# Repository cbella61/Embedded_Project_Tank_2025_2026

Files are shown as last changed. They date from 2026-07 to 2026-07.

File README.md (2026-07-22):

# Wi-Fi Remote-Controlled Tank

Embedded project for a Wi-Fi remote-controlled tank. An ESP32 controller reads two joysticks and two buttons, then sends UDP commands to an Arduino Uno R4 WiFi mounted on the tank. The Arduino controls the tracks, turret rotation and elevation, and the cannon relay.

> YouTube video: [Project demonstration](https://youtu.be/Sw5uwZuhA9w)

> Project presentation: [Group presentation](docs/tank_wifi_embedded_project.pdf)

## Features

- differential drive for the two tracks.
- horizontal turret rotation using a stepper motor.
- turret elevation using two mirrored servo motors.
- logical zeroing of turret and elevation.
- relay control with a limited pulse and cooldown interval.
- Wi-Fi/UDP communication between the controller and the tank.
- safe stop and rearming after a communication loss.
- editable CAD model and exports for manufacturing/3D printing.

## Requirements

### Hardware

The project uses the following hardware components:

| Quantity | Component | Purpose |
| ---: | --- | --- |
| 1 | Arduino Uno R4 WiFi | Tank controller and Wi-Fi access point |
| 1 | ESP32 Dev Module | Handheld controller |
| 1 | Emakefun PS2X & Motor Drive Board | Drives the DC motors and servos; includes a PCA9685 PWM chip |
| 2 | DC motors with tracks | Tank movement |
| 1 | 28BYJ-48 stepper motor with driver | Horizontal turret rotation |
| 2 | TowerPro SG90 servos, or equivalent | Turret elevation |
| 2 | Analog joystick modules | Driving, turret rotation, and elevation |
| 2 | Momentary push buttons | Zeroing and relay control |
| 1 | 5 V relay module | Controls the cannon load |
| 1 | 7.4 V battery | Tank and servo power supply |
| - | Wires, connectors, screws, and printed parts | Wiring and mechanical assembly |

For pin assignments, power supply, jumpers, and safety precautions, see the [wiring guide](docs/tank_shield_wiring_guide.md) and its [PDF version](docs/tank_shield_wiring_guide.pdf).

### Software

- [Visual Studio Code](https://code.visualstudio.com/) with the PlatformIO extension, or PlatformIO Core.
- Arduino framework, installed automatically by PlatformIO.
- appropriate USB drivers for the serial ports of both boards.
- [Autodesk Fusion 360](https://www.autodesk.com/products/fusion-360/overview) on Windows or alternative softwares (like [FreeCAD](https://www.freecad.org/)) on Linux, to design and edit the CAD model.
- [OrcaSlicer](https://github.com/SoftFever/OrcaSlicer) to prepare the parts for 3D printing.

The repository includes the project's application code, including the local `PWMController` and `motorController` drivers. Platform dependencies (Arduino core, WiFiS3, and WiFi/ESP32) are provided by the PlatformIO-selected frameworks and are not duplicated in this repository.

### Tools used by the team

- Visual Studio Code and PlatformIO for firmware development and upload.
- Autodesk Fusion 360 for the mechanical CAD design and editable assemblies.
- OrcaSlicer for slicing and preparing the components for 3D printing.

## Project Layout

```text
.
├── tank/                       # Arduino Uno R4 WiFi firmware on the tank
│   ├── src/                    # UDP receiver, tracks, turret, and relay
│   └── lib/                    # Local PCA9685 and motor-shield drivers
├── controller-esp32/           # ESP32 handheld-controller firmware
│   └── src/                    # Joystick reading and UDP transmission
├── cad/                        # Source files, editable assemblies, and 3D exports
│   ├── source/                 # Parametric Fusion 360/OpenSCAD sources
│   ├── stl/                    # 3D-printable parts
│   └── reference/              # Technical notes and component references
├── docs/                       # Project presentation, wiring guide and motor-shield manual
└── README.md                   # This guide
```

## Essential Wiring

| Function | Connection |
| --- | --- |
| Left track | Shield port `M3` |
| Right track | Shield port `M1` |
| Turret stepper driver | Arduino `D2`–`D5` to `IN1`–`IN4`, with a common GND |
| Elevation servo A | Shield port `S5` |
| Elevation servo B | Shield port `S6` |
| Relay | `D7` signal, 5 V, and GND |
| Controller joystick 1 | ESP32 GPIO `34` and `32` |
| Controller joystick 2 | ESP32 GPIO `35` and `33` |
| Zero button | ESP32 GPIO `25` to GND |
| Fire button | ESP32 GPIO `26` to GND |

Do not power motors and servos from USB alone. Before the first test, lift the tracks off the ground and follow the verification section of the [wiring guide](docs/tank_shield_wiring_guide.md).

## Build, Flash, and Run

### 1. Setup

1. Clone the repository and open its root folder in VS Code/PlatformIO.
2. Connect the Arduino Uno R4 WiFi to the PC using USB.
3. Connect the ESP32 to the PC using USB.
4. Verify that the hardware connections match the wiring guide.

### 2. Build

From PowerShell in the repository root:

```powershell
pio run -d tank
pio run -d controller-esp32
```

Alternatively, use the **Build** command in PlatformIO after opening `tank` and `controller-esp32`, respectively.

### 3. Flash

Upload each firmware to its corresponding board:

```powershell
pio run -d tank --target upload
pio run -d controller-esp32 --target upload
```

If both boards are connected, select the correct serial port in PlatformIO or temporarily add `upload_port` to the relevant `platformio.ini` file.

### 4. Run

1. Power the tank on: the Arduino and shield initialize the motors and create the `Tank_AP` access point on UDP port `4210`.
2. Power the ESP32 controller on while keeping both joysticks centered.
3. The controller calibrates the joysticks and connects to `Tank_AP` automatically.
4. Once the system receives consecutive neutral commands, the actuators are armed.

## User Guide

| Control | Action |
| --- | --- |
| Joy1 Y | Forward/reverse driving |
| Joy1 X | Differential steering or turn-in-place |
| Joy2 X | Horizontal turret rotation |
| Joy2 Y | Raise/lower the turret |
| Zero button (GPIO25) | Sets the logical zero position of turret and elevation |
| Fire button (GPIO26) | Activates a 200 ms relay pulse |

The relay only accepts a new command after a 12-second cooldown. If the tank does not receive valid UDP packets within the configured timeout, it stops motion and disables the relay. After a timeout or reconnection, release the buttons and center the joysticks to allow rearming.

## Documentation and Materials

- [Editable wiring guide](docs/tank_shield_wiring_guide.md)
- [Wiring guide PDF](docs/tank_shield_wiring_guide.pdf)
- [Emakefun PS2X & Motor Drive Board manual](docs/PS2X_MotorDriveBoard_InstructionManual_V1.4.pdf)
- [YouTube project demonstration](https://youtu.be/Sw5uwZuhA9w)

## Team Members and Contributions

Most of the project work was carried out collaboratively by the whole team. The file and subsystem division below identifies the main responsibility or the most significant contribution of each member; it is not intended to imply that the other members did not participate in, review, test, or support those activities.

| Team member | Contribution |
| --- | --- |
| Francesco Martellla | `controller-esp32/src/main.cpp` and `tank/src/main.cpp`, technical drawing, CAD work with Alice and Selmir, 3D-printing work with Alice |
| Alice Sedioli | `controller-esp32/src/joystickReader.*`, `controller-esp32/src/udpSender.*`, and `tank/src/udpReceiver.*`, UDP communication with Selmir and Christian, CAD work with Francesco and Selmir, 3D-printing work with Francesco |
| Christian Bella | `tank/lib/PWMController/*` and `tank/lib/motorController/*`; UDP communication with Alice and Selmir, component selection, local hardware-library implementation |
| Selmir Kusi | `tank/src/servoTorretta.*` and `tank/src/trackController.*`, UDP communication with Alice and Christian, turret and track control, CAD work with Alice and Francesco |

### Shared contributions

- **Technical drawing:** Francesco prepared the technical drawings.
- **Component selection:** Christian contributed to selecting the electronic and electromechanical components.
- **CAD design:** Alice, Selmir, and Francesco collaborated on the Fusion 360 model design.
- **3D printing:** Alice and Francesco prepared the parts' models using OrcaSlicer and printed them at FabLab UniTrento.
- **UDP communication:** Alice, Selmir, and Christian collaborated on the communication path between the ESP32 controller and the Arduino tank, including packet transmission, reception, and safe timeout behavior.
- **Turret and tracks:** Selmir implemented the turret and track-control logic.
- **Libraries:** Christian implemented the local PWM and motor-control libraries used by the tank firmware.

## License

See [LICENSE](docs/license).

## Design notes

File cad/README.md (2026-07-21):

# Tank 3D model
This folder contains the editable mechanical model of the tank.

## Folder structure

- `source/`: parametric sources and the native Autodesk Fusion file.
- `stl/`: parts ready for 3D printing, generated only after dimension confirmation.
- `reference/`: table of confirmed dimensions and assembly notes.

The model is divided into components:

1. lower deck with battery, Arduino, and DC motor cable routing;
2. upper deck with driver, turret PCB, and vertical cable passage;
3. rotating turret base driven by the stepper motor;
4. upper tilting support actuated by two servos;
5. straight cannon fixed to the tilting section, excluding the lateral straps/bars
   shown in the reference.

## Official mechanical references

The official Arduino UNO R4 WiFi STEP model is kept in
`reference/vendor/arduino_uno_r4_wifi/`. It is used only as a dimensional reference.

The TowerPro SG90 dimensions and the manufacturer link are in
`reference/vendor/towerpro_sg90/README.md`.

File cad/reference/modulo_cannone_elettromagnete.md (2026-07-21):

# Cannon module with electromagnet

## Confirmed functional requirements

- The PCB with the electromagnet, its mechanism and the barrel must be
  embedded in the moving part of the turret.
- This entire assembly must rotate together with the cradle driven by the two
  servos.
- Existing holes on the PCB must be used for attachment; do not invent a
  different drilling pattern.
- The stepper still rotates the entire turret in the XY plane.
- The 50 x 50 x 2 mm PCB of the firing module is part of the moving group.

## Confirmed dimensions

- base material/type: PCB, not a metal plate;
- PCB: 50 x 50 x 2 mm;
- diameter of the four holes: 3.5 mm;
- center of each hole 5 mm from the two adjacent PCB edges; coordinates from
  the PCB center are therefore X = ±20 mm and Y = ±20 mm;
- complete cannon in the solenoid area: maximum external diameter 20 mm;
- cylindrical/tubular barrel: external diameter 10 mm and wall thickness 1 mm,
  therefore internal diameter 8 mm;
- barrel protrusion from the cannon exit: 46 mm;
- total height from the PCB bottom face to the top of the assembly: 23 mm.

- lateral envelope of the electromagnet body: about 25 mm;
- width shown in the top view: about 30 mm;

These last values must not be used yet to generate geometry.

## Assembly choice to verify on prototype

The PCB will be centered on the moving cradle and fastened using the four
confirmed holes. The final position of the elevation axis relative to the
module can be adjusted in the parameters after verifying the real balance.

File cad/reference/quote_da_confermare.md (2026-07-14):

# Quote da confermare

Unità di progetto: millimetri.

| Gruppo | Quota | Valore confermato |
| --- | --- | --- |
| Telaio | Lunghezza totale del piano inferiore | 170 mm (comunicata come "height") |
| Telaio | Larghezza totale del piano inferiore | 160 mm |
| Telaio | Spessore del piano inferiore | 3 mm |
| Telaio | Luce verticale tra superficie superiore del piano inferiore e fondo del piano superiore | 40 mm |
| Fissaggio | Numero colonnine | 4 |
| Fissaggio | Diametro esterno colonnine | 10 mm (scelta autorizzata) |
| Fissaggio | Distanza centro colonnine dai bordi | 12 mm (scelta autorizzata) |
| Fissaggio | Viteria | M3 |
| Viteria disponibile | Misure utilizzabili | M2, M2.5, M3, M4 e M5; scegliere in base al componente |
| Fissaggio | Diametro fori passanti | 3,2 mm |
| Fissaggio | Sede dado M3 | 5,8 mm tra facce, profondità 2,6 mm |
| Fissaggio | Posizione sede dado M3 | In cima a ogni colonnina |
| Fissaggio al telaio | Metodo | Fascette attorno a due aste trasversali |
| Fissaggio al telaio | Dimensioni asole | 10 x 5 mm, asse lungo Est-Ovest |
| Fissaggio al telaio | Posizioni asole dal bordo Sud | 10, 25, 75 e 90 mm, allineamento laterale centrale |
| Piano superiore | Lunghezza | 170 mm |
| Piano superiore | Larghezza | 160 mm |
| Piano superiore | Spessore | 3 mm |
| Passacavi | Diametro e posizione del foro inferiore | da confermare |
| Passacavi | Diametro e posizione del foro superiore | da confermare |
| Elettronica | Modello e ingombro della batteria | da confermare |
| Elettronica | Arduino | UNO R4 WiFi ABX00087 con shield Emakefun sovrapposta; profilo ufficiale 68,58 x 53,34 mm, quattro fori Ø3,2 mm; STEP ufficiale disponibile |
| Elettronica | Apertura Arduino | una apertura quadrata 25 x 25 mm nel piano superiore, sopra S1-S8 e D2-D7; centro X=33,33 mm, Y=45,71 mm |
| Elettronica | Passaggio pacco batteria PCB cannone | 60 x 33 mm nel piano superiore, centro X=-52,5 mm, Y=-15 mm; case fotografato 59 x 32 mm, gioco 0,5 mm per lato, lato lungo verso Nord |
| Elettronica | Posizione supporto batteria | angolo Sud-Ovest; lato da 100 mm verso Nord, 5 mm da Ovest e 20 mm da Sud; centro X=-52,5 mm, Y=-15 mm |
| Elettronica | Supporto batteria nello stage completo | pareti 2,5 mm alte 17 mm unite al piano inferiore; il piano da 3 mm è il fondo; nessuna vite o colla dedicata |
| Elettronica | Supporto batteria autonomo | stage alternativo con fondo proprio da 2 mm; ingombro 100 x 45 x 19 mm |
| Elettronica | Apertura cavi supporto batteria | tratto utile di 10 mm sulla parete lunga Est, subito dopo la parete corta Sud |
| Elettronica | Posizione Arduino + shield | angolo Nord-Est, rotazione 90 gradi antioraria, jack DC verso Sud; 20 mm da Est e 5 mm da Nord; centro X=33,33 mm, Y=45,71 mm |
| Elettronica | Modello e ingombro del driver motori | da confermare |
| Elettronica | Dimensioni e schema dei fori della PCB torretta | da confermare |
| Torretta | Riferimento stepper | 28BYJ-48, quote CAD provvisorie e modificabili |
| Torretta | Base rotante | diametro 70 mm, spessore 6 mm, provvisoria |
| Elevazione | Servomotori | 2 TowerPro SG90 coricati, corpo 22,7 x 12,2 x 27 mm; inserimento laterale removibile |
| Elevazione | Fissaggio SG90 | due slitte esterne e due barrette M2.5 per lato; zona centrale libera per il cavo |
| Elevazione | Cinematica | due perni orizzontali coassiali, diametro 6 mm; movimento del cannone lungo Z |
| Elevazione | Corsa proposta | -10° / +35°, da verificare sul prototipo |
| Azimut | Corsa torretta | da -180° a +180° rispetto allo zero; 360° complessivi ma non continui |
| Azimut | Arresto | gestito dal software contando i passi dello stepper; nessuna battuta meccanica nel CAD |
| Cablaggio SG90 | Cavo, connettore e passaggi | 2 cavi, ciascuno a 3 fili, profilo circa 4 x 1 mm; uscita slitta 5 x 2 mm; connettore 7 x 3 mm; passaggio comune 8 x 6 mm, connettori infilati uno alla volta |
| Cablaggio cannone | Fili, connettore e passaggio mobile | 2 fili allungabili; connettore 5 x 3 mm; passaggio sotto culla 6 x 4 mm |
| Cablaggio torretta | Guida azimut | canale anulare completo tipo clock-spring, raggio medio 28 mm, larghezza libera 8 mm, fondo continuo Z locale 20-23 mm, altezza libera 7 mm e uscita fissa 8 x 6 mm a 45°; nessuna razza nella pista |
| Cannone | Forma | unico corpo rettilineo solidale alla culla mobile |
| Cannone | Lunghezza e sezione esterna | 175 x 40 x 14 mm, asse a 70 mm dal retro; provvisorio |
| Modulo di sparo | Parti mobili | piastra con elettromagnete, meccanismo e canna ruotano tutti con la culla |
| Modulo di sparo | Metodo di fissaggio | usare i quattro fori esistenti della PCB mobile |
| Modulo di sparo | PCB | 50 x 50 x 2 mm, non metallica |
| Modulo di sparo | Zona con solenoide | cannone completo Ø20 mm in questa zona |
| Modulo di sparo | Canna | tubolare, Ø10 mm esterno, parete 1 mm, Ø8 mm interno, sporgenza 46 mm dall'uscita |
| Modulo di sparo | Altezza complessiva | 23 mm dalla faccia inferiore della PCB alla sommità |
| Modulo di sparo | Fori PCB | Ø3,5 mm; centri a 5 mm dai due bordi adiacenti; interassi 40 x 40 mm |

## Regola di modellazione

Ogni valore inserito nel CAD deve essere riconducibile a una misura comunicata
e confermata oppure a una prima proposta espressamente autorizzata e marcata
come provvisoria. Eventuali giochi di stampa sono parametri separati e dichiarati.

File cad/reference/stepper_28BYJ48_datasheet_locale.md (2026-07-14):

# Riferimento locale stepper 28BYJ-48

Fonte analizzata il 13 luglio 2026:
`C:\Users\selmi\Downloads\stepper.pdf`.

Il PDF è un datasheet generico del **28BYJ-48 5 V**. È utile come riferimento,
ma non sostituisce la misura del motore fisico perché esistono varianti tra
produttori.

## Quote leggibili nel disegno

- corpo cilindrico: Ø28 mm;
- profondità nominale del corpo: 19 mm;
- interasse dei due fori: 35 ± 0,2 mm;
- due fori nominali: Ø4,2 mm;
- raggio esterno delle alette attorno ai fori: R3,5 mm;
- albero nominale: Ø5 mm con una faccia piana;
- quota trasversale della parte piatta: 3 mm nel disegno;
- sporgenza complessiva albero: 10 ± 0,5 mm;
- tratto utile indicato: 6 ± 0,2 mm;
- collare frontale indicato: 1,5 mm.

Il disegno conferma quindi i valori provvisori già usati per interasse 35 mm e
fori Ø4,2 mm. Non conferma invece che l'esemplare reale dell'utente abbia
esattamente la stessa faccia piana e la stessa sporgenza.

## Conseguenza per l'adattatore

Un foro tondo Ø5,3 mm non può trasmettere la coppia dello stepper. Per il
prototipo serve una delle seguenti soluzioni, da scegliere dopo la misura
dell'albero reale:

1. sede a D aderente all'albero;
2. mozzo con grano laterale;
3. mozzo a morsetto diviso.

Prima di modificare il CAD vanno misurati sul motore fisico:

- diametro massimo dell'albero;
- distanza tra faccia piana e lato opposto;
- lunghezza utile realmente inseribile nel mozzo.

## Vecchio riferimento disponibile

È presente anche
`C:\Users\selmi\Downloads\Carroarmato\STL\adattatore_stepper_torretta_v2_3_RC2.stl`.
La mesh ha ingombro circa 73 x 63,22 x 22 mm ed è utile come riferimento
geometrico, ma non è parametrica e le sue quote interne non vanno considerate
confermate senza confronto con il motore reale.

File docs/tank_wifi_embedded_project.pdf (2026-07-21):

EMBEDDED SYSTEMS PROJECT A.A. 2025-26

# Remotely controlled tank

Wireless manual control with explicit software safety states.
Fully functional, network-controlled robotic vehicle with articulated movement and precise aiming capabilities.

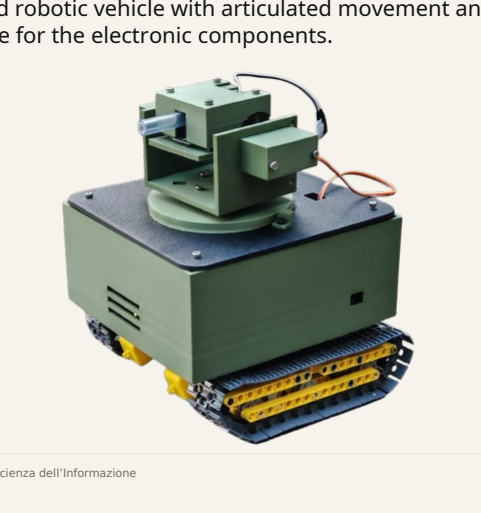
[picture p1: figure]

Featuring a custom 3D printed case for the electronic components.

Università degli Studi di Trento · Dipartimento di Ingegneria e Scienza dell’Informazione | 01

EMBEDDED SYSTEMS PROJECT A.A. 2025-26

# Hardware components overview

- Arduino Uno R4 WiFi: Main microcontroller and web server host.
- ESP32-DevKitC-32UE: Microcontroller used for the remote control.

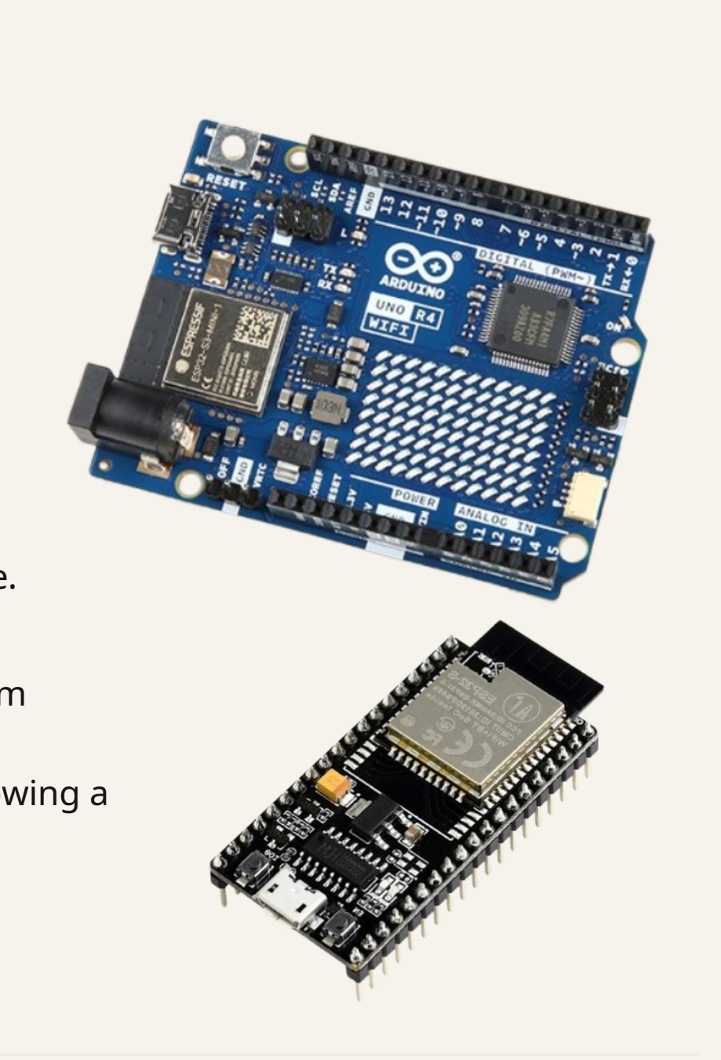
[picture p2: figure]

- EmakeFun PS2X & Motor Drive Board: Primary motor driver interface.
- DC Motors (2x): Independent track movement.
- Servomotors (2x): Vertical inclination of the cannon muzzle (maximum vertical rotation: 45 ). °
- Stepper Motor & Driver: Lateral/horizontal rotation of the turret, allowing a rotation of 45 on both sides. °
- HV Electromagnetic Cannon DIY Kit: Main firing mechanism (DC3V).
- Battery: 3300mAh capacity, 7.4V.
Hardware overview | 01

# Architecture overview

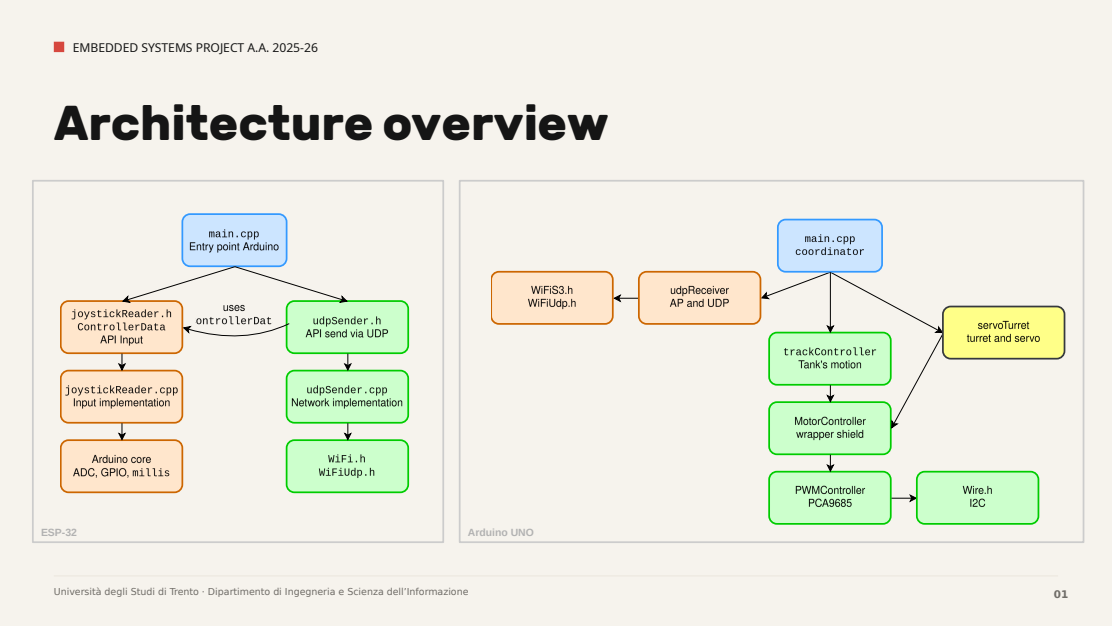
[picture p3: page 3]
ESP-32; Arduino UNO

EMBEDDED SYSTEMS PROJECT A.A. 2025-26

# Code showcase

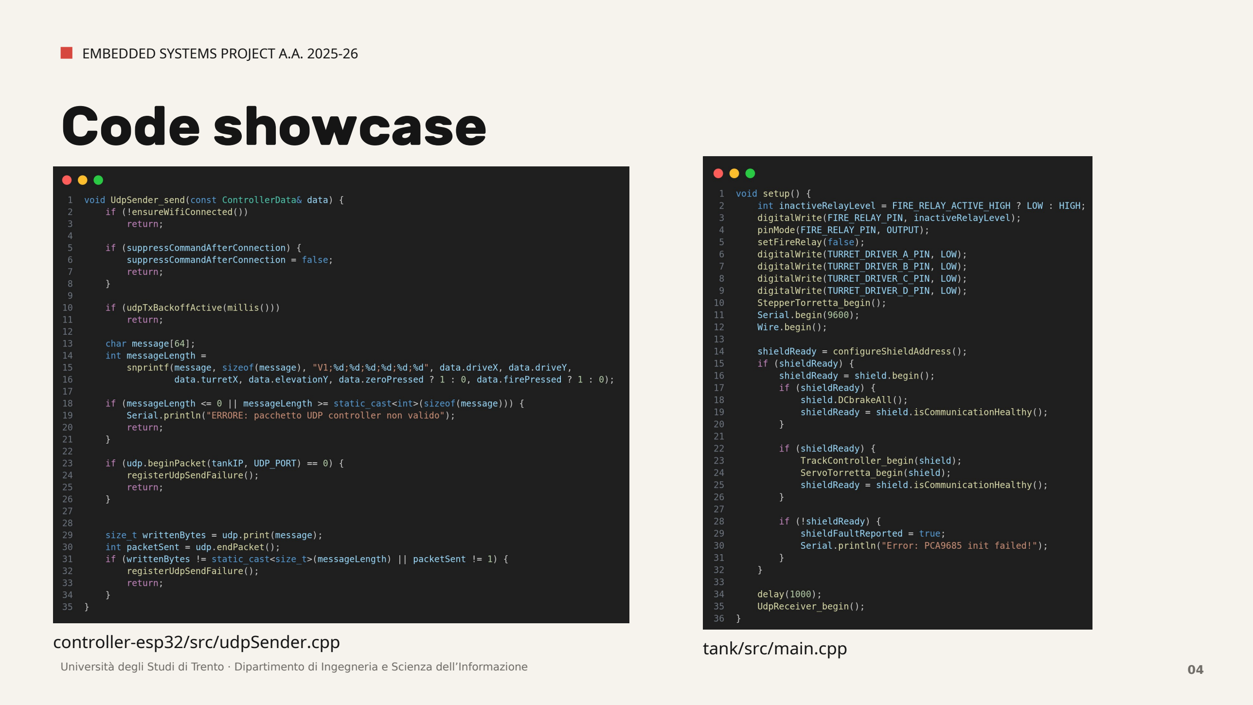
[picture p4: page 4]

EMBEDDED SYSTEMS PROJECT A.A. 2025-26

Università degli Studi di Trento · Dipartimento di Ingegneria e Scienza dell’Informazione | 04
controller-esp32/src/udpSender.cpp | tank/src/main.cpp

EMBEDDED SYSTEMS PROJECT A.A. 2025-26

# Testing

Università degli Studi di Trento · Dipartimento di Ingegneria e Scienza dell’Informazione | 05
- Physical device: checking if actual result = desired result;
- | Serial monitor: checking log messages using pio device monitor command; “ | ”
- Wireshark: UDP packet sniffing to check protocol integrity.

# Results

- Physical device: tank works as intended;
- UDP protocol: works fine in low-traffic networks; delays happen only if the device is around networks with 20+
| devices.

EMBEDDED SYSTEMS PROJECT A.A. 2025-26

# Improvements and future work

01
WEB
INTERFACE

Basic HTML/CSS
dashboard using
Arduino Uno R4 WiFi's
web server capabilities.
Adds flexibility and is
easier to debug.

02
FPV CAMERA

Adding an ESP32-CAM
or a dedicated FPV
camera for better
aiming and driving.
The video feed would be
separate from the
control data (Wi-Fi for
control, analog/2.4GHz
for video).

03
TARGET
DISTANCE
MEASUREMENT
Using an ultrasound
sensor and an
accelerometer to
calculate the tank's
distance from the
target and turret
incline.

04
AUTOMATED
FIRING SYSTEM

Implementation of a
state machine for
automatic loading and
firing of the cannon.
Università degli Studi di Trento · Dipartimento di Ingegneria e Scienza dell’Informazione | 06

05
UDP V2

Congestion control,
Forward Error
Correction (FEC), and
multipath support.

EMBEDDED SYSTEMS PROJECT A.A. 2025-26

# Thanks for the attention

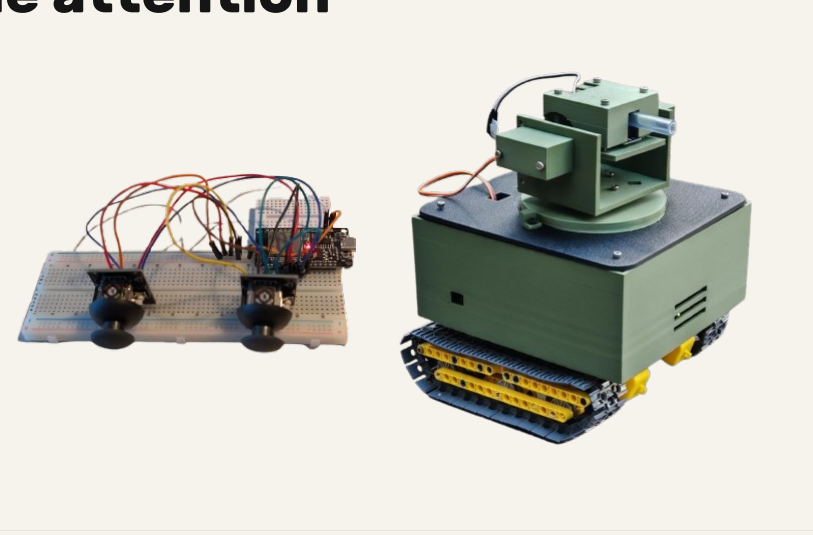
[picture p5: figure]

Team members:
- Christian BELLA
- Selmir KUSI
- Francesco MARTELLA
- Alice SEDIOLI

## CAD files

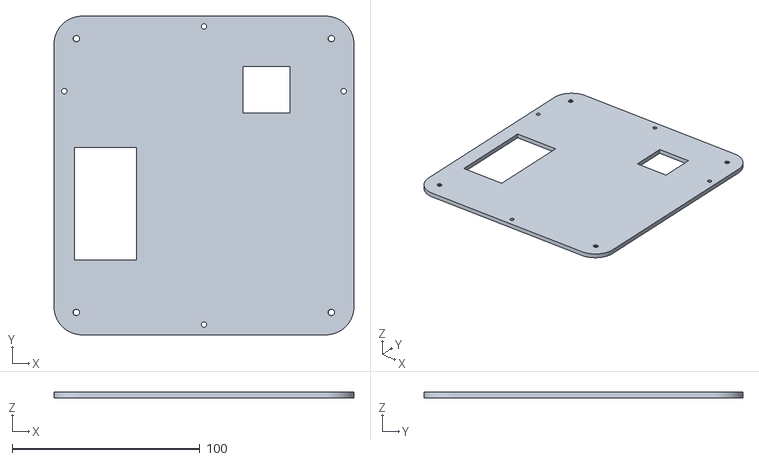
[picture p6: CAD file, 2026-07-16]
cad/stl/02_Piano_superiore.stl
160.0 x 170.0 x 3.00

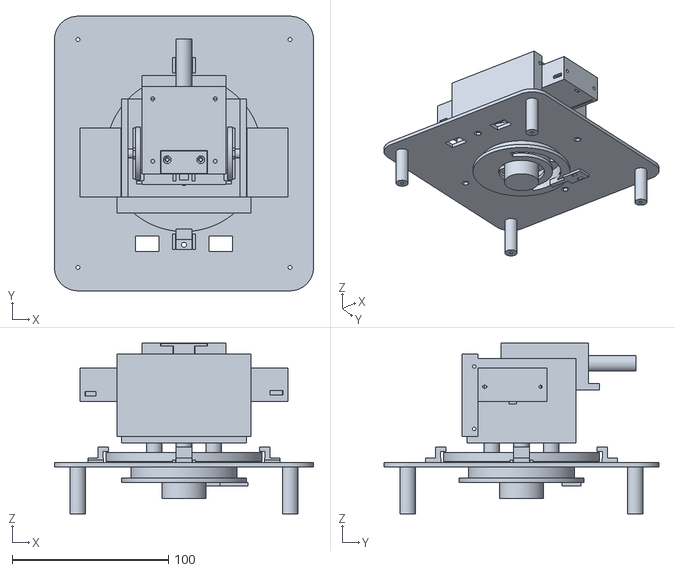
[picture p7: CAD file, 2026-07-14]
cad/stl/Torret_funzionale.stl
166.0 x 176.0 x 109.5

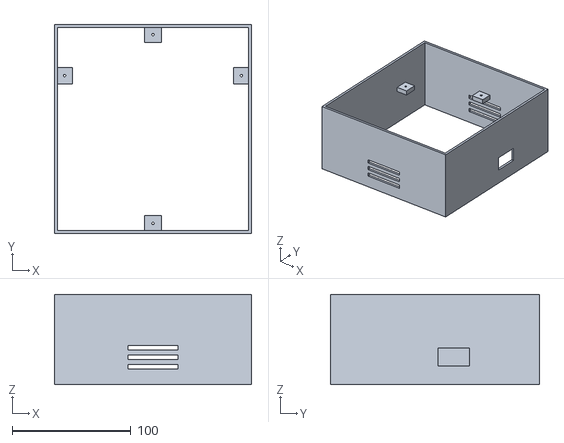
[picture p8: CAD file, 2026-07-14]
cad/stl/03_Guscio_laterale_continuo_carro.stl
166.0 x 176.0 x 76.0

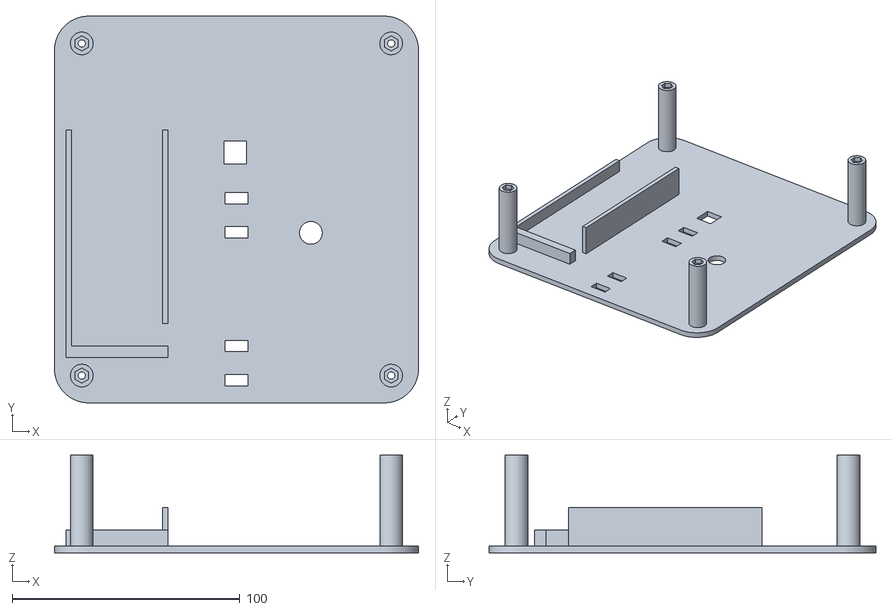
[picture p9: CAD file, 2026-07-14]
cad/stl/01_Piano_inferiore_colonnine_M3_supporto_batteria_integrato.stl
160.0 x 170.0 x 43.0

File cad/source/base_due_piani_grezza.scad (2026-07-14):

// Assieme grezzo dei due piani: solo quote confermate.
// Nessun foro e nessuna colonnina vengono aggiunti senza autorizzazione.
// Unita: millimetri.

piano_lunghezza = 170;
piano_larghezza = 160;
piano_spessore = 3;
luce_tra_piani = 40;

module piano() {
    translate([-piano_larghezza / 2, -piano_lunghezza / 2, 0])
        cube([piano_larghezza, piano_lunghezza, piano_spessore]);
}

color("LightSteelBlue")
    piano();

color("Gainsboro")
    translate([0, 0, piano_spessore + luce_tra_piani])
        piano();

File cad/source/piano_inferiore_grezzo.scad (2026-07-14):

// Piano inferiore grezzo: quote confermate, nessun foro ancora quotato.
// Unita: millimetri.

piano_lunghezza = 170;
piano_larghezza = 160;
piano_spessore = 3;

// Origine al centro della faccia inferiore.
translate([-piano_larghezza / 2, -piano_lunghezza / 2, 0])
    cube([piano_larghezza, piano_lunghezza, piano_spessore]);

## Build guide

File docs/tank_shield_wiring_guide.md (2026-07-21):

# Tank Shield - Wiring Guide and Configuration

Firmware: `Embedded_Project_Tank_2025_2026`  
Tank: Arduino Uno R4 WiFi + Emakefun PS2X & Motor Drive Board  
Controller: ESP32 Dev Module  
Updated: July 19, 2026

## 1. General map

| Function | Connection | Notes |
| --- | --- | --- |
| Left track | Shield `M3` | 2-wire DC motor |
| Right track | Shield `M1` | 2-wire DC motor |
| Unused port | Shield `M2` | Left unused because on tested hardware it rotated by itself |
| Horizontal turret | `D2-D5` to driver `IN1-IN4` | 5-wire stepper with external driver |
| Elevation servo A | Shield `S5` | Logical angle direct `0-47` degrees |
| Elevation servo B | Shield `S6` | Mirrored motion: `90 - angle` |
| Cannon relay | `D7` to relay `S` pin | Power terminals `COM` and `NO` |
| Communication | WiFi AP + UDP | `Tank_AP`, password `12345678`, port `4210` |

Motors and servos are driven by the shield. The horizontal turret and the
relay use Arduino digital pins routed via the shield connectors.

## 2. DC tracks

Each yellow motor has two wires and must use both terminals of the same motor
port. Do not connect one motor wire to GND.

| Track | Port | Connection |
| --- | --- | --- |
| Left | `M3` | Two motor wires into the two terminals of `M3` |
| Right | `M1` | Two motor wires into the two terminals of `M1` |

If a track spins in the wrong direction, swap its two wires or change in
`tank/src/trackController.h`:

```cpp
#define LEFT_TRACK_INVERTED false
#define RIGHT_TRACK_INVERTED false
```

Set `true` only for the side that needs to reverse direction.

## 3. Horizontal turret

The 5-wire stepper is not connected directly to the shield: its external driver
powers the coils. Arduino only sends the digital sequence on the four inputs.

| Arduino/shield | Turret driver |
| --- | --- |
| `D2` | `A` / `IN1` |
| `D3` | `B` / `IN2` |
| `D4` | `C` / `IN3` |
| `D5` | `D` / `IN4` |
| `GND` | `GND` driver |

Power the driver with the voltage required by its module. Its GND must be
connected to the common GND of Arduino, shield, ESP32 and any power supplies
connected via cable and the buck converter.

The firmware uses a single-phase full-step sequence:

```text
A -> B -> C -> D -> A       rotation one direction
D -> C -> B -> A -> D       rotation the other direction
```

Speed depends on `TURRET_STEP_INTERVAL_MS` in `tank/src/servoTorreta.h`:
higher values slow the turret. Current value is `2 ms`.

## 4. Elevation servos

The servo connector on the shield has three pins: `G` = ground, `V` = supply,
`S` = signal. Always check the letters printed on the board before inserting
the connector.

| Servo | Port | Current command |
| --- | --- | --- |
| Servo A | `S5` | from `0` to `47` degrees |
| Servo B | `S6` | from `90` to `43` degrees, i.e. `90 - angle A` |

The value shown on the tank serial is the logical angle of servo A. Servo B
automatically receives the mirrored command.

Configuration in `tank/src/servoTorreta.cpp`:

```cpp
#define ELEVATION_MIN_ANGLE 0
#define ELEVATION_MAX_ANGLE 47
#define ELEVATION_MIRROR_BASE 90
```

## 5. Relay and cannon

### Control side

| Relay | Arduino/shield |
| --- | --- |
| `+` | `5V` |
| `-` | `GND` |
| `S` | `D7` |

### Power side

Use `COM` and `NO`, not `NC`:

```text
cannon positive supply -> COM relay
NO relay                    -> cannon positive input
negative supply             -> cannon negative input
```

Looking at the module as in the project photo, the upper terminal toward the
cannon is `NO`. Always verify the `NO/COM/NC` labeling on the PCB before
powering.

The relay receives a `200 ms` pulse. At least `12 seconds` must elapse between
two firings, even if the button is pressed multiple times.

## 6. ESP32 controller

### Physical connections

| Component | Physical input | ESP32 pin |
| --- | --- | --- |
| Joy1 drive | X axis | GPIO `34` |
| Joy1 drive | Y axis | GPIO `32` |
| Joy2 turret | X axis | GPIO `35` |
| Joy2 turret | Y axis | GPIO `33` |
| Zero button | signal | GPIO `25`, button to GND |
| Fire button | signal | GPIO `26`, button to GND |

Buttons use `INPUT_PULLUP`: released = HIGH, pressed = LOW.

### Swap X/Y in software

Joysticks are mounted rotated. The firmware swaps X and Y on both:

```cpp
#define DRIVE_SWAP_X_Y true
#define TURRET_SWAP_X_Y true
```

After the swap, logical commands sent over UDP are:

| Logical command | Read physical pin | Function |
| --- | --- | --- |
| `driveX` | GPIO `32` | differential steering |
| `driveY` | GPIO `34` | forward/backward |
| `turretX` | GPIO `33` | horizontal turret |
| `elevationY` | GPIO `35` | elevation servo |

To invert only the direction of an axis use the four constants
`DRIVE_X_INVERTED`, `DRIVE_Y_INVERTED`, `TURRET_X_INVERTED` and
`ELEVATION_Y_INVERTED` in `controller-esp32/src/joystickReader.cpp`. Joy1 axis
orientation is corrected only here; on the tank only the two physical motor
inversions remain (`LEFT/RIGHT_TRACK_INVERTED`).

## 7. Joystick calibration

On ESP32 startup:

1. Leave both joysticks centered.
2. Firmware waits `600 ms`.
3. Reads each axis `80` times, 2 ms apart, and computes the real center. Full
   calibration therefore takes about `1.24 s` plus small processing overhead.
4. Calibration is accepted only if each axis is near `512` (maximum deviation
   `70`) and does not oscillate more than `40` points during sampling.
5. Remaps the measured center to `512`, keeping extremes `0-1023`. If
   calibration is invalid, only the safe command is sent and a restart with
   joysticks centered is required.
6. Even with valid calibration, before arming the controls it requires neutral
   joysticks and released buttons for `400 ms`.

Deadzones are not all equal: each filter serves a different purpose.

| Filter | Value and dead zone |
| --- | --- |
| Joy1 drive on controller | `DRIVE_INPUT_DEADZONE = 20`: less than `20` points from calibrated center |
| Joy2 turret/elevation on controller | `TURRET_INPUT_DEADZONE = 80`: less than `80` points from calibrated center |
| Tracks on the tank | `TRACK_COMMAND_DEADZONE = 100`: less than `100` points from UDP center, before and after mixing |
| Turret and servos on the tank | `TURRET_JOYSTICK_DEADZONE = 200`: less than `200` points from UDP center |

The small Joy1 deadzone avoids adding an excessive dead zone to the tank
protection. Do not touch joysticks during initial calibration and during the
arming wait.

## 8. Differential drive and speed

Joy1 Y controls forward/backward linearly and can reach maximum speed. Joy1 X
controls steering only. There are no additional curves, bands or intermediate
steering thresholds.

```text
forward  = decode(driveY)
turn     = decode(driveX)
left     = constrain(forward + turn, -512, +512)
right    = constrain(forward - turn, -512, +512)
```

`decode()` scales the input from `0-1023`, subtracts center `512` and applies
the tank deadzone. With joystick Y forward both tracks get the same command;
with Joy1 X one side speeds up and the other slows down. With only Joy1 X the
two tracks turn in opposite directions and the tank spins in place. `constrain()`
prevents the sum from exceeding the allowed command range.

Main configurations in `tank/src/trackController.h`:

```cpp
#define TRACK_COMMAND_DEADZONE 100
#define LEFT_TRACK_MIN_PWM 900
#define RIGHT_TRACK_MIN_PWM 900
```

When a reverse command is requested, each track is first braked to zero PWM and
re-enabled after `30 ms` (`TRACK_REVERSE_DEAD_TIME_MS` in
`tank/src/trackController.cpp`). The pause applies even if the joystick briefly
passes through center before the opposite direction.

## 9. UDP protocol and rate

The controller sends about `50 packets per second`, one every `20 ms`:

```text
V1;driveX;driveY;turretX;elevationY;zero;fire
```

Example:

```text
V1;512;900;512;512;0;0
```

The tank keeps the last valid command. If it does not receive valid packets for
`200 ms` it centers all axes, deactivates buttons and stops movements. On the
first timeout it returns the safe command before performing a new `WiFiS3`
polling, so it does not intentionally add a network wait to the normal stop.

On startup the tank remains disarmed. If `WiFi.beginAP()` or opening the UDP
socket fail, it does not enter `while(true)`: it remains in the safe state and
retries every `3 seconds`. When AP and UDP are ready, and after any boot,
timeout or network fault, the tank requests `3` consecutive packets with all
axes within `+/-20` of center and buttons released before rearming actuators.

If the ESP32 loses `Tank_AP`, it does not block the program: it stops sending,
tries to reconnect every `3 seconds` and allows the tank to enter the safety
timeout. When WiFi returns it updates the IP from the gateway, reopens UDP on
port `4210`, requests controller neutrality again and resumes sending only after
rearming.

The ESP32 error `endPacket(): could not send data: 12` is `ENOMEM`: a WiFi
stack buffer is temporarily exhausted, it is not a V1 string overflow. An
isolated error leaves the socket open; after `3` consecutive failures the
controller closes the socket and tries to reopen it after `200 ms` without
forcing an immediate WiFi reconnection. Radio sleep is disabled to reduce
latency. If it appears together with `WiFi lost`, check power and motor
electrical noise first: software cannot eliminate brown-out or EMI.

## 10. Power

According to the Emakefun V1.4 manual:

- the shield can be powered from the Arduino DC jack with `6-12 V`;
- a `7.4 V` battery on the Arduino jack is therefore within the expected range;
- with the servo jumper at `5V`, servos use the shield's 5 V regulator;
- with the jumper at `EX`, servos use the external power input;
- the manual specifies up to `3 A` for the shield's 5 V rail, but the actual
  consumption of the two servos depends on load and stall peaks.

Recommended configuration when servos jerk or reset Arduino:

```text
battery 7.4 V -> Arduino DC jack
battery 7.4 V -> buck converter input
buck regulated output -> shield external servo power
servo jumper -> EX
GND buck -> GND Arduino/shield
```

Adjust and measure the buck output before connecting servos. Use the voltage
allowed by the servos, typically 5-6 V. Do not connect two different supplies
to the same positive rail and do not power motors or servos from USB alone.

For WiFi problems during driving, keep logic/controller power separate from the
motor branch when possible, with a correct common ground. Add a suitable
electrolytic nearby the shield (approx. 470--1000 uF, correct voltage and
polarity), bypass ceramics and noise-suppression capacitors at motor terminals;
twist motor wires and keep them away from the ESP32 antenna. Before adding
components, verify current and voltage limits of battery, shield and motors.

> Important: a software timeout is not an electrical switch. To guarantee a
stop even if WiFiS3/I2C block or the Uno resets, provide a hardware enable/OE/
STBY default-off, or an E-stop that physically removes motor and relay enable.

## 11. Where to change behavior

| Change | File | Constant/function |
| --- | --- | --- |
| Swap X/Y Joy1 | `controller-esp32/src/joystickReader.cpp` | `DRIVE_SWAP_X_Y` |
| Swap X/Y Joy2 | `controller-esp32/src/joystickReader.cpp` | `TURRET_SWAP_X_Y` |
| Invert an axis | `controller-esp32/src/joystickReader.cpp` | constants `*_INVERTED` |
| Joy1 deadzone (drive) | `controller-esp32/src/joystickReader.cpp` | `DRIVE_INPUT_DEADZONE` |
| Joy2 deadzone | `controller-esp32/src/joystickReader.cpp` | `TURRET_INPUT_DEADZONE` |
| Track deadzone | `tank/src/trackController.h` | `TRACK_COMMAND_DEADZONE` |
| Single track speed | `tank/src/trackController.h` | `LEFT/RIGHT_TRACK_MIN/MAX_PWM`, `LEFT/RIGHT_TRACK_PWM_PERCENT` |
| Pause before reversing | `tank/src/trackController.cpp` | `TRACK_REVERSE_DEAD_TIME_MS` |
| Track direction | `tank/src/trackController.h` | `LEFT/RIGHT_TRACK_INVERTED` |
| Turret speed | `tank/src/servoTorreta.h` | `TURRET_STEP_INTERVAL_MS` |
| Elevation limits | `tank/src/servoTorreta.cpp` | `ELEVATION_MIN/MAX_ANGLE` |
| Mirror second servo | `tank/src/servoTorreta.cpp` | `ELEVATION_MIRROR_BASE` |
| Relay pulse duration | `tank/src/main.cpp` | `FIRE_RELAY_PULSE_MS` |
| Pause between shots | `tank/src/main.cpp` | `FIRE_RELAY_COOLDOWN_MS` |
| Tank AP/UDP retry | `tank/src/udpReceiver.cpp` | `NETWORK_RETRY_INTERVAL_MS` |
| Tank UDP rearm | `tank/src/udpReceiver.cpp` | `REARM_NEUTRAL_PACKET_COUNT`, `REARM_NEUTRAL_TOLERANCE` |
| UDP timeout | `tank/src/udpReceiver.cpp` | `CONNECTION_TIMEOUT_MS` |
| Controller send rate | `controller-esp32/src/main.cpp` | `UDP_SEND_INTERVAL_MS` |
| ESP32 `ENOMEM` recovery | `controller-esp32/src/udpSender.cpp` | `UDP_SEND_FAILURE_LIMIT`, `UDP_SOCKET_RECOVERY_INTERVAL_MS` |
| Track I2C refresh | `tank/src/trackController.h` | `TRACK_COMMAND_REFRESH_INTERVAL_MS` |

## 12. Quick diagram

```text
ESP32 controller
  GPIO34 <- Joy1 physical X -> driveY after swap
  GPIO32 <- Joy1 physical Y -> driveX after swap
  GPIO35 <- Joy2 physical X -> elevationY after swap
  GPIO33 <- Joy2 physical Y -> turretX after swap
  GPIO25 <- zero button to GND
  GPIO26 <- fire button to GND
                 |
                 | WiFi UDP, every 20 ms
                 v
Arduino Uno R4 WiFi + shield
  M3     -> left track DC motor, both wires
  M1     -> right track DC motor, both wires
  D2-D5  -> IN1-IN4 turret stepper driver
  S5     -> elevation servo A
  S6     -> elevation servo B
  D7     -> S relay cannon
  Relay  -> COM + NO, NO toward cannon
```

## 13. Pre-power checks

- No motor wire connected directly to GND.
- Turret driver and Arduino share common GND.
- Servo connectors oriented according to `G/V/S` printed on the shield.
- Measure the buck converter with a multimeter before connecting servos.
- Servo jumper set consistently: `5V` or `EX`.
- Relay connected to `COM` and `NO`, not to `NC`.
- Joysticks centered during ESP32 startup.
- Tracks lifted for the first test of timeout or `ENOMEM` recovery.
- Measure controller supply while tracks start/reverse; if `WiFi lost` appears,
  fix the power branch and wiring first.

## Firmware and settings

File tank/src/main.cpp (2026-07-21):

/*
 * TANK MAIN
 *
 * This file does not directly perform all movements: it coordinates modules.
 *
 * Operation method:
 * 1. In setup() initialize the relay, turret, PCA9685 shield and UDP receiver.
 * 2. In loop() read the last command received from the ESP32 controller.
 * 3. Dispatch each part of the command to the appropriate module:
 *    - driveX/driveY     -> differential tracks
 *    - turretX           -> horizontal turret D2-D5
 *    - elevationY        -> servos S5/S6
 *    - firePressed       -> relay D7
 *    - zeroPressed       -> logical zeroing
 * 4. If the controller stops sending packets for too long, stop the motors.
 */

#include <Arduino.h>
#include <Wire.h>

#include "motorController.h"
#include "servoTorreta.h"
#include "trackController.h"
#include "udpReceiver.h"

// Digital pin connected to the relay module.
#define FIRE_RELAY_PIN 7

#define FIRE_RELAY_PIN 7

// true: relay active with HIGH. false: relay active with LOW.
#define FIRE_RELAY_ACTIVE_HIGH true

// Duration of the fire pulse: the relay is not kept continuously on.
#define FIRE_RELAY_PULSE_MS 200

// Minimum time between one shot and the next.
#define FIRE_RELAY_COOLDOWN_MS 12000

// ===== SERIAL MONITOR =====

// Print coordinates once per second to avoid filling the console.
#define COORDINATE_PRINT_INTERVAL_MS 1000

// Shared PCA9685 shield between the tracks and elevation servo.
// Frequency is 50 Hz because it is compatible with servos.
static MotorController shield(50);

// Diventa true solo se la PCA9685 viene trovata su I2C.
static bool shieldReady = false;
static bool shieldFaultReported = false;

// Stato del relay sparo.
static bool fireRelayActive = false;
static unsigned long fireRelayStartTime = 0;
static unsigned long lastFireShotTime = 0;
static bool fireRelayHasShot = false;

// Check whether a device responds at an I2C address.
static bool i2cDevicePresent(uint8_t address) {
    Wire.beginTransmission(address);
    return Wire.endTransmission() == 0;
}

// Automatically select the PCA9685 address on the shield.
// Some shields use different addresses, so the code tries common ones.
static bool configureShieldAddress() {
    static const uint8_t candidateAddresses[] = {0x60, 0x40, 0x7F};

    for (uint8_t address : candidateAddresses) {
        if (i2cDevicePresent(address)) {
            shield.setAddress(address);
            Serial.print("Shield PCA9685: I2C 0x");
            Serial.println(address, HEX);
            return true;
        }
    }

    Serial.println("ERROR: PCA9685 shield not detected");
    return false;
}

// Set the correct electrical level for the fire relay.
static void setFireRelay(bool active) {
    int level =
        active ? (FIRE_RELAY_ACTIVE_HIGH ? HIGH : LOW) : (FIRE_RELAY_ACTIVE_HIGH ? LOW : HIGH);

    digitalWrite(FIRE_RELAY_PIN, level);
    fireRelayActive = active;
}

// Generate a single fire pulse for each button press.
// Uses the rising edge and then waits 12 seconds before accepting another shot.
static void updateFireRelay(bool firePressed, bool connected) {
    static bool lastFirePressed = false;
    static bool fireInputArmed = false;

    // After timeout or loss of connection the relay must turn off immediately.
    // A subsequent connection cannot reuse a button press that remained active:
    // first observe the release of the Fire button.
    if (!connected) {
        setFireRelay(false);
        fireInputArmed = false;
        lastFirePressed = false;
        return;
    }

    if (!fireInputArmed) {
        if (!firePressed) {
            fireInputArmed = true;
        }

        // Still record the received level: when Fire is held down
        // during reconnection it will not be interpreted as a rising edge.
        lastFirePressed = firePressed;
        return;
    }

    bool newFirePress = firePressed && !lastFirePressed;
    bool cooldownFinished =
        !fireRelayHasShot || millis() - lastFireShotTime >= FIRE_RELAY_COOLDOWN_MS;

    if (newFirePress && cooldownFinished) {
        setFireRelay(true);
        fireRelayStartTime = millis();
        lastFireShotTime = fireRelayStartTime;
        fireRelayHasShot = true;
    }

    if (fireRelayActive && millis() - fireRelayStartTime >= FIRE_RELAY_PULSE_MS) {
        setFireRelay(false);
    }

    lastFirePressed = firePressed;
}

// Stop all motion in case of UDP timeout.
// Tracks depend on the shield; the turret (D2-D5) can be stopped at any time.
static void stopAllMotion() {
    // TrackController_stop() e' innocua prima dell'inizializzazione e va tentata anche
    // dopo un fault I2C: una PCA9685 che ha conservato l'ultimo PWM puo' essere tornata
    // raggiungibile per un istante. Il controller limita internamente i retry di brake.
    TrackController_stop();
    StepperTorretta_stop();
}

// A NACK or a short I2C read makes the tank disarmed until reset.
// Do not attempt to automatically rearm a PCA9685 that has just reported an error.
static void enterShieldFault() {
    if (!shieldReady) {
        return;
    }

    // Spegni prima le uscite che non dipendono da I2C e tenta l'ultimo brake della
    // PCA9685 prima di segnare la shield come non utilizzabile.
    setFireRelay(false);
    StepperTorretta_stop();
    TrackController_stop();
    shieldReady = false;

    if (!shieldFaultReported) {
        shieldFaultReported = true;
        Serial.println("ERROR: PCA9685 communication; tank disarmed until reset");
    }
}

void setup() {
    // Preload the GPIO latches in a safe state before making them outputs.
    // This way D7 and D2-D5 do not wait for Serial or boot delay to receive the
    // first level defined by the firmware.
    int inactiveRelayLevel = FIRE_RELAY_ACTIVE_HIGH ? LOW : HIGH;
    digitalWrite(FIRE_RELAY_PIN, inactiveRelayLevel);
    pinMode(FIRE_RELAY_PIN, OUTPUT);
    setFireRelay(false);

    digitalWrite(TURRET_DRIVER_A_PIN, LOW);
    digitalWrite(TURRET_DRIVER_B_PIN, LOW);
    digitalWrite(TURRET_DRIVER_C_PIN, LOW);
    digitalWrite(TURRET_DRIVER_D_PIN, LOW);
    StepperTorretta_begin();

    Serial.begin(9600);

    // Initialize and brake the PCA9685 before the serial delay: after a reset
    // the PWM board can briefly retain the last command to the tracks.
    Wire.begin();
    shieldReady = configureShieldAddress();
    if (shieldReady) {
        // Avvia PWM, spegne le uscite motore e passa la shield ai moduli.
        shieldReady = shield.begin();
        if (shieldReady) {
            shield.DCbrakeAll();
            shieldReady = shield.isCommunicationHealthy();
        }

        if (shieldReady) {
            TrackController_begin(shield);
            ServoTorretta_begin(shield);
            shieldReady = shield.isCommunicationHealthy();
        }

        if (!shieldReady) {
            shieldFaultReported = true;
                    Serial.println("ERROR: PCA9685 initialization failed; tank disarmed");
        }
    }

    // The delay is only for the serial console; it should not delay motor braking.
    delay(1000);

    // Start WiFi access point and UDP reception.
    UdpReceiver_begin();
    Serial.println("Tank ready");
}

void loop() {
    // Riceve l'ultimo comando del controller ESP32.
    // Se non arrivano pacchetti, UdpReceiver_update() restituisce valori sicuri centrati.
    TankCommand command = UdpReceiver_update();

    // The release of Zero must be observed after boot or reconnection before
    // accepting a new press event.
    static bool lastZeroPressed = false;
    static bool zeroInputArmed = false;

    // Non inviare alcun nuovo comando agli attuatori se il link e' scaduto.
    // Spegnimento relay e arresto vengono eseguiti prima di ogni altro aggiornamento.
    if (!command.connected || !shieldReady) {
        setFireRelay(false);
        stopAllMotion();
        updateFireRelay(false, false);
        lastZeroPressed = false;
        zeroInputArmed = false;

        if (shieldReady && !shield.isCommunicationHealthy()) {
            enterShieldFault();
        }
    } else {
        // The horizontal turret is direct: uses D2-D5, so it does not depend on the PCA9685.
        StepperTorretta_updateJoystick(command.turretX);
        // Tracks and elevation depend on the PWM shield.
        if (!shieldReady) {
            shieldFaultReported = true;
            Serial.println("ERROR: PCA9685 communication; tank disarmed until reset");
        }
            } else {
                ServoTorretta_updateJoystick(command.elevationY);
                if (!shield.isCommunicationHealthy()) {
                    enterShieldFault();
                }
            }
        }

        // Fire e Zero restano inibiti se una scrittura PWM ha appena fallito.
        if (shieldReady) {
            updateFireRelay(command.firePressed, true);

            // Zero resets the turret logical position once per press.
            // After a reconnection, a press that is already held is ignored until release.
            if (!zeroInputArmed) {
                if (!command.zeroPressed) {
                    zeroInputArmed = true;
                }
                lastZeroPressed = command.zeroPressed;
            } else {
                if (command.zeroPressed && !lastZeroPressed) {
                    StepperTorretta_setZero();
                    ServoTorretta_setZero();
                }
                lastZeroPressed = command.zeroPressed;
            }
        } else {
            updateFireRelay(false, false);
            lastZeroPressed = false;
            zeroInputArmed = false;
        }
    }

    // Mostra coordinate e stato connessione una volta al secondo.
    static unsigned long lastPrintTime = 0;
    if (millis() - lastPrintTime > COORDINATE_PRINT_INTERVAL_MS) {
        lastPrintTime = millis();

        Serial.print("RX ");
        Serial.print(command.connected && shieldReady ? "OK" : "DISARMED");
        Serial.print(" | drive X=");
        Serial.print(command.driveX);
        Serial.print(" Y=");
        Serial.print(command.driveY);
        Serial.print(" | turret X=");
        Serial.print(command.turretX);
        Serial.print(" angolo=");
        Serial.print(StepperTorretta_getAngle());
        Serial.print("deg | elev Y=");
        Serial.print(command.elevationY);
        Serial.print(" servo=");
        Serial.print(ServoTorretta_getAngle());
        Serial.print("deg | zero=");
           Serial.print(command.zeroPressed ? "PRESSED" : "off");
        Serial.print(" fire=");
           Serial.println(command.firePressed ? "PRESSED" : "off");
    }
}

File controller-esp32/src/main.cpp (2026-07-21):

#include <Arduino.h>

#include "joystickReader.h"
#include "udpSender.h"

/*
 * ESP32 CONTROLLER MAIN
 *
 * Operation method:
 * 1. Configure joysticks/buttons.
 * 2. Connect to the WiFi network created by the tank.
 * 3. Every 50 ms read inputs and send a UDP packet to the tank.
 * 4. If WiFi is lost, continue the loop and automatically attempt reconnection.
 */

#define UDP_SEND_INTERVAL_MS 50

static unsigned long lastUdpSendTime = 0;

void setup() {
    Serial.begin(115200);

    // Configure inputs before connecting to the tank network.
    JoystickReader_begin();
    UdpSender_begin();

    Serial.println("Controller ready");
}

void loop() {
    unsigned long now = millis();
    if (now - lastUdpSendTime < UDP_SEND_INTERVAL_MS) {
        return;
    }
    lastUdpSendTime = now;

    // Read joysticks/buttons and send a UDP command every 50 ms.
    ControllerData data = JoystickReader_read();
    UdpSender_send(data);
}

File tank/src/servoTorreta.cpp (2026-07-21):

/*
 * TURRET OPERATION METHOD
 *
 * Horizontal turret:
 * - the external driver receives four signals: A, B, C, D
 * - on each step we energize a single output at a time
 * - forward sequence: A -> B -> C -> D -> A
 * - backward sequence: D -> C -> B -> A -> D
 *
 * Elevation:
 * - the two servos are connected to the shield PCA9685 on S5 and S6
 * - the first servo receives the normal angle
 * - the second servo receives a mirrored angle: ELEVATION_MIRROR_BASE - angle
 */

#include "servoTorreta.h"

// The horizontal turret stops at half a revolution per side.
#define TURRET_MIN_ANGLE -180
#define TURRET_MAX_ANGLE 180

// The two elevation servos must not exceed this mechanical range.
// Required range for the turret: 0 degrees = low, 47 degrees = high.
#define ELEVATION_MIN_ANGLE 0
#define ELEVATION_MAX_ANGLE 47
#define ELEVATION_MIRROR_BASE 90
#define ELEVATION_SERVO_A S5
#define ELEVATION_SERVO_B S6

// Logical center of joysticks after conversion 0-1023.
#define JOYSTICK_CENTER 512

// Servos are updated slower than the stepper for stability.
#define SERVO_INTERVAL_MS 30

// Convert degree limits to step limits.
#define TURRET_MIN_STEPS ((STEPS_PER_REV * TURRET_MIN_ANGLE) / 360)
#define TURRET_MAX_STEPS ((STEPS_PER_REV * TURRET_MAX_ANGLE) / 360)

// Pointer to the shield provided by main. Used only for servos S5/S6.
static MotorController* shield = nullptr;

// Logical state of the horizontal stepper.
static int currentSteps = 0;
static int stepIndex = 0;
static unsigned long lastStepTime = 0;
static bool stepperEnabled = false;

// Logical state of the elevation servos.
static int currentServoAngle = 0;
static unsigned long lastServoUpdateTime = 0;

// Physically write a phase to the turret driver.
// This is the same single-coil sequence used in the old Arduino direct code.
static void writeTurretStep(int phase) {
    switch (phase) {
    case 0:
        digitalWrite(TURRET_DRIVER_A_PIN, HIGH);
        digitalWrite(TURRET_DRIVER_B_PIN, LOW);
        digitalWrite(TURRET_DRIVER_C_PIN, LOW);
        digitalWrite(TURRET_DRIVER_D_PIN, LOW);
        break;
    case 1:
        digitalWrite(TURRET_DRIVER_A_PIN, LOW);
        digitalWrite(TURRET_DRIVER_B_PIN, HIGH);
        digitalWrite(TURRET_DRIVER_C_PIN, LOW);
        digitalWrite(TURRET_DRIVER_D_PIN, LOW);
        break;
    case 2:
        digitalWrite(TURRET_DRIVER_A_PIN, LOW);
        digitalWrite(TURRET_DRIVER_B_PIN, LOW);
        digitalWrite(TURRET_DRIVER_C_PIN, HIGH);
        digitalWrite(TURRET_DRIVER_D_PIN, LOW);
        break;
    case 3:
        digitalWrite(TURRET_DRIVER_A_PIN, LOW);
        digitalWrite(TURRET_DRIVER_B_PIN, LOW);
        digitalWrite(TURRET_DRIVER_C_PIN, LOW);
        digitalWrite(TURRET_DRIVER_D_PIN, HIGH);
        break;
    }

    stepperEnabled = true;
}

// Step one position to the right, if not at the software limit.
static void stepRight() {
    if (currentSteps >= TURRET_MAX_STEPS) {
        StepperTorretta_stop();
        return;
    }

    stepIndex = (stepIndex + 1) % 4;
    writeTurretStep(stepIndex);
    currentSteps++;
}

// Step one position to the left, if not at the software limit.
static void stepLeft() {
    if (currentSteps <= TURRET_MIN_STEPS) {
        StepperTorretta_stop();
        return;
    }

    stepIndex = (stepIndex + 3) % 4;
    writeTurretStep(stepIndex);
    currentSteps--;
}

void StepperTorretta_begin() {
    // Pins D2-D5 are exposed by the shield as Arduino digital pins.
    pinMode(TURRET_DRIVER_A_PIN, OUTPUT);
    pinMode(TURRET_DRIVER_B_PIN, OUTPUT);
    pinMode(TURRET_DRIVER_C_PIN, OUTPUT);
    pinMode(TURRET_DRIVER_D_PIN, OUTPUT);

    // Immediately force all outputs LOW and start from phase 0.
    stepperEnabled = true;
    StepperTorretta_stop();
    currentSteps = 0;
    stepIndex = 0;
}

void StepperTorretta_updateJoystick(int joystickValue) {
    unsigned long now = millis();

    // Limit the speed: if not enough time has passed, do not step.
    if (now - lastStepTime < TURRET_STEP_INTERVAL_MS) {
        return;
    }

    lastStepTime = now;

    // Joy2 X below center turns left, above center turns right.
    // Inside the deadzone the driver is turned off to avoid vibration.
    if (joystickValue < JOYSTICK_CENTER - TURRET_JOYSTICK_DEADZONE) {
        stepLeft();
    } else if (joystickValue > JOYSTICK_CENTER + TURRET_JOYSTICK_DEADZONE) {
        stepRight();
    } else {
        StepperTorretta_stop();
    }
}

void StepperTorretta_setZero() {
    // Reset the logical position without moving the motor.
    currentSteps = 0;
}

void StepperTorretta_stop() {
    if (!stepperEnabled) {
        return;
    }

    // All outputs low: the driver does not energize any coil.
    digitalWrite(TURRET_DRIVER_A_PIN, LOW);
    digitalWrite(TURRET_DRIVER_B_PIN, LOW);
    digitalWrite(TURRET_DRIVER_C_PIN, LOW);
    digitalWrite(TURRET_DRIVER_D_PIN, LOW);
    stepperEnabled = false;
}

int StepperTorretta_getAngle() {
    return (currentSteps * 360L) / STEPS_PER_REV;
}

void ServoTorretta_begin(MotorController& controller) {
    // Store the shield pointer and move servos to the initial position.
    shield = &controller;
    ServoTorretta_setZero();
}

void ServoTorretta_updateJoystick(int joystickValue) {
    unsigned long now = millis();

    // Servos are not updated on every loop: 30 ms is more stable.
    if (now - lastServoUpdateTime < SERVO_INTERVAL_MS) {
        return;
    }

    lastServoUpdateTime = now;

    int nextAngle = currentServoAngle;

    // Joy2 Y lowers/raises one degree at a time.
    if (joystickValue < JOYSTICK_CENTER - TURRET_JOYSTICK_DEADZONE) {
        nextAngle--;
    } else if (joystickValue > JOYSTICK_CENTER + TURRET_JOYSTICK_DEADZONE) {
        nextAngle++;
    }

    if (nextAngle != currentServoAngle) {
        ServoTorretta_setAngle(nextAngle);
    }
}

void ServoTorretta_setAngle(int angle) {
    if (shield == nullptr) {
        return;
    }

    // Clamp the angle within mechanical limits and command the two mirrored servos.
    currentServoAngle = constrain(angle, ELEVATION_MIN_ANGLE, ELEVATION_MAX_ANGLE);
    shield->servoPairTurn(ELEVATION_SERVO_A, ELEVATION_SERVO_B, currentServoAngle,
                          ELEVATION_MIRROR_BASE);
}

void ServoTorretta_setZero() {
    ServoTorretta_setAngle(ELEVATION_MIN_ANGLE);
}

int ServoTorretta_getAngle() {
    return currentServoAngle;
}

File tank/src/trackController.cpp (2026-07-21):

/*
 * DC TRACKS OPERATION METHOD
 *
 * Each yellow motor has only two wires. The shield provides:
 * - direction: forward or backward
 * - speed: PWM from the configured minimum to maximum per track
 *
 * The code no longer uses stepper phases. It now simply sends PWM to motors
 * M1 and M3, with differential mixing to steer like a tank.
 */

#include "trackController.h"

// Puntatore al driver PWM ricevuto dal main in TrackController_begin().
static MotorController* motorController = nullptr;

// Before reversing a track, firmware applies a short pause at zero PWM.
// The value must be validated on the real driver: it's a software improvement,
// not a replacement for a hardware cutoff in case of I2C bus failure.
#define TRACK_REVERSE_DEAD_TIME_MS 30

// La deadzone deve lasciare almeno un comando positivo e uno negativo disponibili.
static_assert(TRACK_COMMAND_DEADZONE > 0 && TRACK_COMMAND_DEADZONE < DRIVE_JOYSTICK_CENTER,
              "TRACK_COMMAND_DEADZONE must stay inside the joystick range");

struct TrackMotorState {
    // Last direction passed to DCRun(). It's a software request, not a motor measurement.
    int lastRequestedDirection;
    // Last direction before DCbrake(). It remains stored even if the joystick
    // returns to center, so an immediate reversal still respects the pause time.
    int directionBeforeStop;
    int pendingDirection;
    int pendingSpeed;
    bool waitingForReverse;
    unsigned long stoppedAt;
};

static TrackMotorState leftTrackState = {0, 0, 0, 0, false, 0};
static TrackMotorState rightTrackState = {0, 0, 0, 0, false, 0};

// Avoid constantly rewriting the same four I2C registers while the joystick is
// still. Periodic refresh still preserves the shield health control; a stop
// bypasses this limitation.
static int lastDriveX = DRIVE_JOYSTICK_CENTER;
static int lastDriveY = DRIVE_JOYSTICK_CENTER;
static bool hasLastDriveCommand = false;
static unsigned long lastTrackCommandTime = 0;
static bool stopCommandIssued = false;
static unsigned long lastStopCommandTime = 0;

static TrackMotorState* stateForTrackMotor(int motorNumber) {
    if (motorNumber == LEFT_TRACK_MOTOR) {
        return &leftTrackState;
    }

    if (motorNumber == RIGHT_TRACK_MOTOR) {
        return &rightTrackState;
    }

    return nullptr;
}

// Decode a UDP axis 0--1023 into a signed command centered on zero.
// Example: 512 becomes 0, 1023 becomes about +511, 0 becomes -512.
// Axis inversion is the responsibility of the ESP32 controller, not the tank.
static int decodeDriveAxis(int value) {
    int centered = constrain(value, 0, 1023) - DRIVE_JOYSTICK_CENTER;

    // Primo filtro lato tank: protegge anche da sender UDP diversi dall'ESP32.
    // Il filtro finale di applyTrackMotorCommand() resta necessario dopo forward +/- turn.
    if (abs(centered) < TRACK_COMMAND_DEADZONE) {
        centered = 0;
    }

    return centered;
}

// Bring a track to zero PWM and cancel any pending reversal.
static void stopTrackMotor(int motorNumber) {
    if (motorController == nullptr) {
        return;
    }

    TrackMotorState* state = stateForTrackMotor(motorNumber);
    motorController->DCbrake(motorNumber);

    if (state != nullptr) {
            // Do not clear directionBeforeStop: it is used if after center the opposite
            // direction is requested.
        if (state->lastRequestedDirection != 0) {
            state->directionBeforeStop = state->lastRequestedDirection;
            state->stoppedAt = millis();
        }

        state->lastRequestedDirection = 0;
        state->pendingDirection = 0;
        state->pendingSpeed = 0;
        state->waitingForReverse = false;
    }
}

// Map forward/backward linearly: Joy1 Y must be able to reach maximum.
static int mapLinearTrackSpeed(int magnitude, int minPwm, int maxPwm) {
    int fullMagnitude = DRIVE_JOYSTICK_CENTER - 1;
    int limitedMagnitude = constrain(magnitude, TRACK_COMMAND_DEADZONE, fullMagnitude);

    return map(limitedMagnitude, TRACK_COMMAND_DEADZONE, fullMagnitude, minPwm, maxPwm);
}

// Apply a signed command to a track, including PWM and safe reversal pause.
static void applyTrackMotorCommand(int motorNumber, bool inverted, int command, int minPwm,
                                   int maxPwm, int pwmPercent) {
    if (motorController == nullptr) {
        return;
    }

    TrackMotorState* state = stateForTrackMotor(motorNumber);
    if (state == nullptr) {
        return;
    }

    command = constrain(command, -DRIVE_JOYSTICK_CENTER, DRIVE_JOYSTICK_CENTER);
    minPwm = constrain(minPwm, 0, MAX_SPEED);
    maxPwm = constrain(maxPwm, minPwm, MAX_SPEED);
    pwmPercent = constrain(pwmPercent, 0, 150);

    // Second tank-side filter: mixing can leave a single track small even when
    // forward and turn were both outside their individual deadzones.
    if (abs(command) < TRACK_COMMAND_DEADZONE) {
        stopTrackMotor(motorNumber);
        return;
    }

    int magnitude = abs(command);

    // Forward/backward and the final motor command remain linear.
    int speed = mapLinearTrackSpeed(magnitude, minPwm, maxPwm);
    speed = constrain(static_cast<int>((static_cast<long>(speed) * pwmPercent) / 100), 0, MAX_SPEED);

    int direction = command > 0 ? FORWARD : BACKWARD;
    if (inverted) {
        direction = direction == FORWARD ? BACKWARD : FORWARD;
    }

    unsigned long now = millis();

    // During the reversal pause keep only the last command, without re-enabling
    // the H-bridge before the minimum time has passed.
    if (state->waitingForReverse) {
        state->pendingDirection = direction;
        state->pendingSpeed = speed;

        if (now - state->stoppedAt < TRACK_REVERSE_DEAD_TIME_MS) {
            return;
        }

        motorController->DCrun(motorNumber, state->pendingDirection, state->pendingSpeed);
        state->lastRequestedDirection = state->pendingDirection;
        state->directionBeforeStop = state->pendingDirection;
        state->waitingForReverse = false;
        return;
    }

    // Do not invert a running motor directly: brake, wait and then reapply.
    if (state->lastRequestedDirection != 0 && state->lastRequestedDirection != direction) {
        motorController->DCbrake(motorNumber);
        state->directionBeforeStop = state->lastRequestedDirection;
        state->lastRequestedDirection = 0;
        state->pendingDirection = direction;
        state->pendingSpeed = speed;
        state->waitingForReverse = true;
        state->stoppedAt = now;
        return;
    }
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

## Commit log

2026-05-20 stepper orizonatle torreta piu wifi tra r4 eil esp32 l esp sara nel altro proggetto
2026-05-21 servo torreta piu alcune modifice
2026-05-21 sistemanto di alcuni file
2026-07-14 proggetto
    file stl
    [01_Piano_inferiore_colonnine_M3_supporto_batteria_integrato.stl, 02_Piano_superiore.stl, Guscio_laterale_continuo_166x176_Z0_Z76_griglie_fronte_retro.stl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]
2026-07-14 allora questo e il giusto gli altri file non servivano
    [Piano_inferiore_colonnine_M3_supporto_batteria_integrato.stl, piano_inferiore_grezzo_senza_fori.stl]
2026-07-14 Update 02_Piano_superiore.stl
    piano 2 modificatp
    [02_Piano_superiore.stl]
2026-07-14 ultimi 2 pezzi mancanti
    torreta e gusxio modificato
    [03_Guscio_laterale_continuo_carro.stl, Torret_funzionale.stl, torretta_modulare_stampabile_v6_doppia_D_5x3x6.f3d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]
2026-07-14 vechio gusccio elliminato
    vechio guscio eliminato
    [Guscio_laterale_continuo_166x176_Z0_Z76_griglie_fronte_retro.stl]
2026-07-16 Nuovi file per buchi
    [02_Piano_superiore.stl]
2026-07-19 modifiche wiring
2026-07-21 documentation improvements and repository cleaning
    [base_colonnine_M3_asole_aperture_superiori_Arduino_pacco_batteria.f3d, base_colonnine_M3_asole_aperture_superiori_Arduino_pacco_batteria.step, base_colonnine_M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]
